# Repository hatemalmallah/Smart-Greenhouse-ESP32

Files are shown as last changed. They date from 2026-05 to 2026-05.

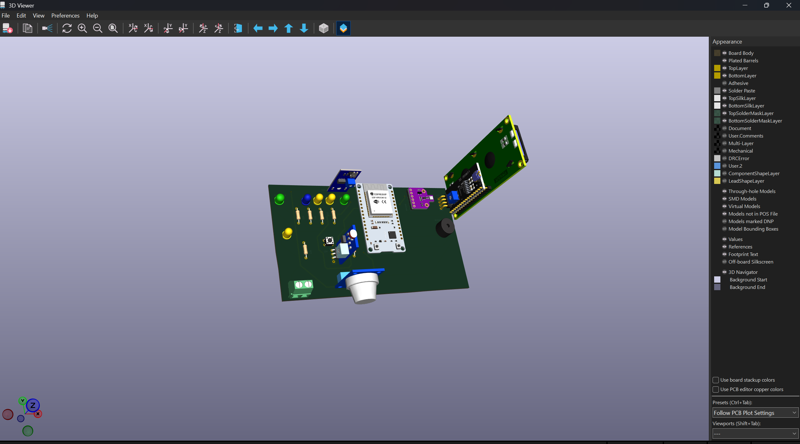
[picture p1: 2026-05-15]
Smart Greenhouse iot/image/3D PCB Design.png

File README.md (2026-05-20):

## Project Overview
This repository contains the hardware design, firmware, and IoT integration for an industrial-grade Smart Greenhouse control system. Unlike standard automated greenhouses, this project is engineered with a strong focus on **system reliability, fault tolerance, and precise actuator control**.

Powered by an **ESP32** microcontroller, the system monitors environmental parameters (Temperature, Humidity, Pressure, Gas, and Soil Moisture) via an I2C-managed **BME680** sensor. It intelligently controls 6 distinct actuators—represented by LEDs in this hardware prototype—simulating the following sub-systems: **Heating System, Cooling System, Water Pump, Grow Light, Ventilation Fan, and Humidifier**. The system manages all of these seamlessly using dual manual/automatic modes.

## Key Technical Highlights
* **Advanced Control Logic:** Implemented **Hysteresis algorithms** for stable, threshold-based actuator switching to prevent relay chattering and system instability.
* **Fault Tolerance & Safety:** Engineered a robust fail-safe mechanism. The system validates sensor data ranges, falls back to the last valid reading upon error, and executes an **Emergency Shutdown** after 5 consecutive invalid retries.
* **Signal Processing:** Utilized a Moving Average Filter (10-sample window) to clean noisy analog signals from sensors like soil moisture, preventing false triggering.
* **IoT & Remote Management:** Features bidirectional remote control via a custom **Telegram Bot API** and **Blynk** dashboard, alongside live data telemetry logged to **ThingSpeak** every 20 seconds for future Machine Learning (Predictive Maintenance) applications.
* **Custom Hardware:** Includes full PCB schematics and routing files designed specifically to handle the microcontroller, sensor bus, and actuator power management reliably.

## Hardware Components
* ESP32 Development Board (30-pin)
* BME680 Environmental Sensor
* LCD 16x2 with I2C module
* LDR Module (4-pin Photoresistor)
* 6x LED (5mm) - *Simulating Actuators*
* 6x Resistor (220 ohm)
* Buzzer (5V)
* MQ-2 Gas Sensor
* Push Button (4-pin)

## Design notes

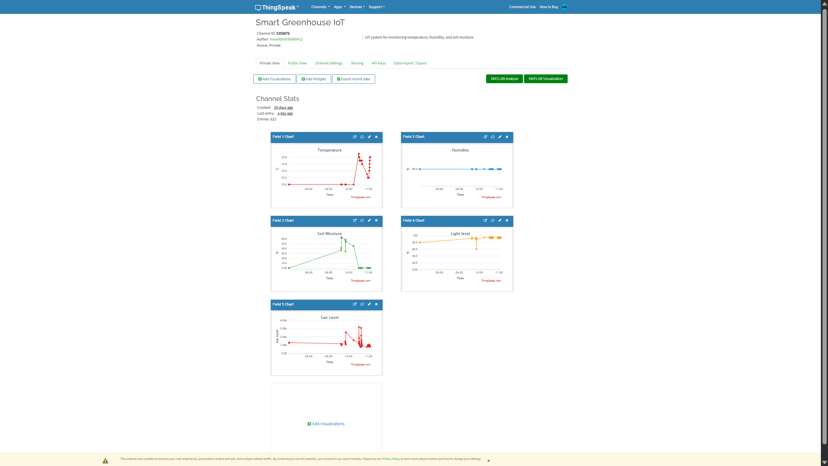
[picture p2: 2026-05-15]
Smart Greenhouse iot/image/Thingspeak .png

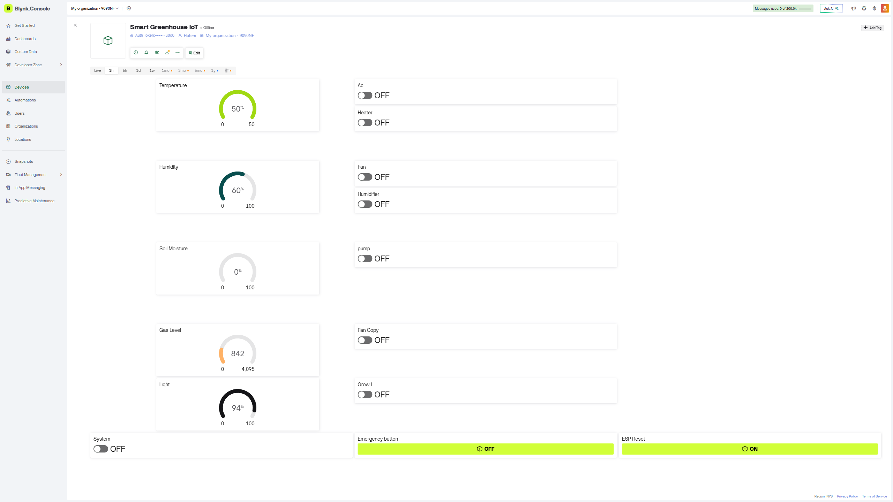
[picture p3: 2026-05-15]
Smart Greenhouse iot/image/Blynk Dashboard.png

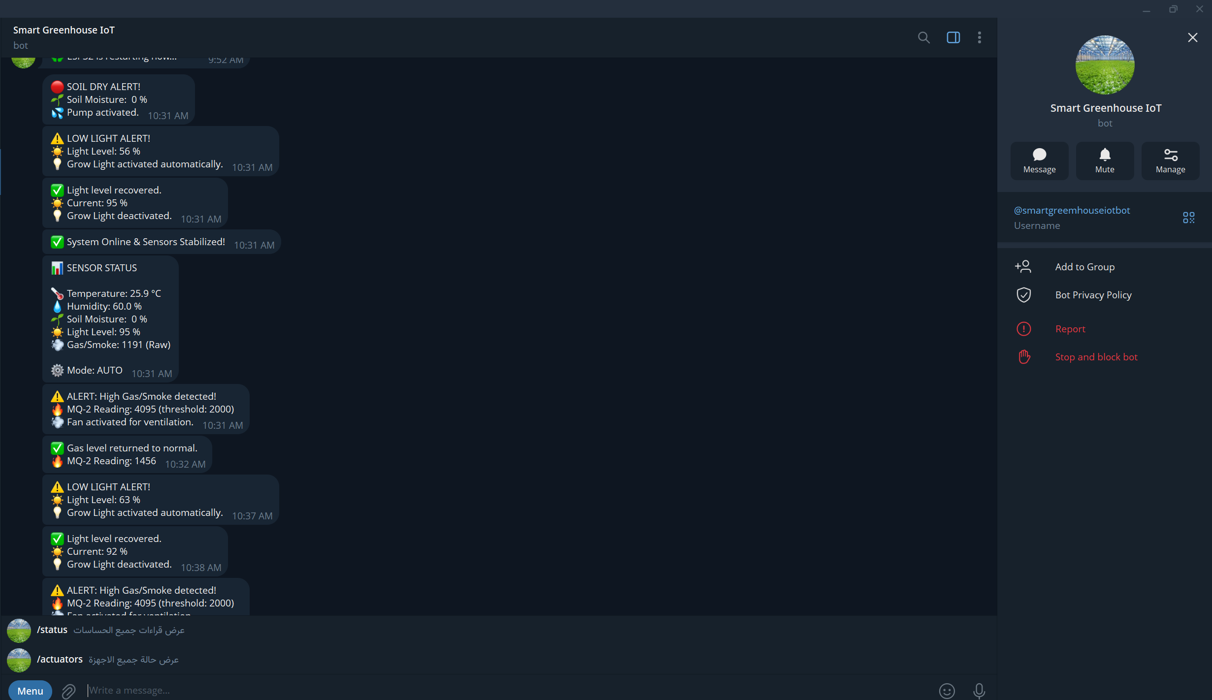
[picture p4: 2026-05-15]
Smart Greenhouse iot/image/Telegram Bot.png

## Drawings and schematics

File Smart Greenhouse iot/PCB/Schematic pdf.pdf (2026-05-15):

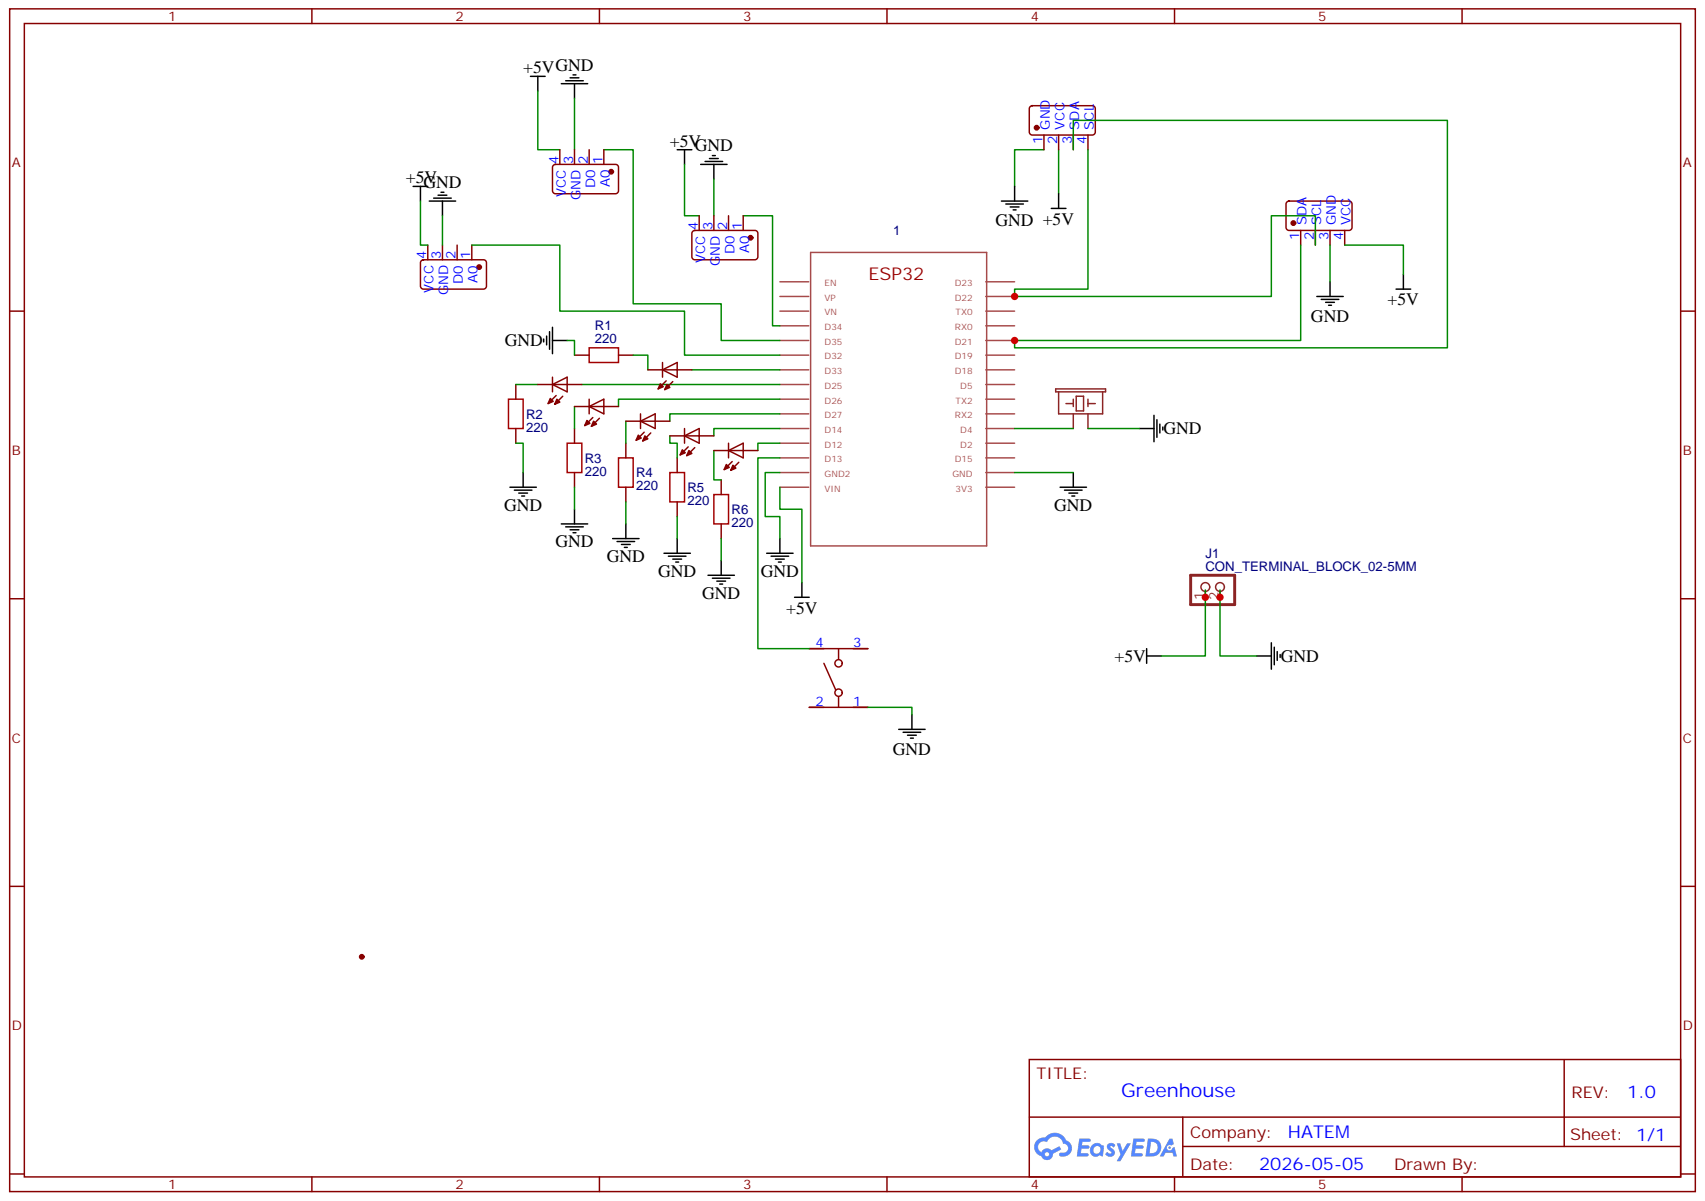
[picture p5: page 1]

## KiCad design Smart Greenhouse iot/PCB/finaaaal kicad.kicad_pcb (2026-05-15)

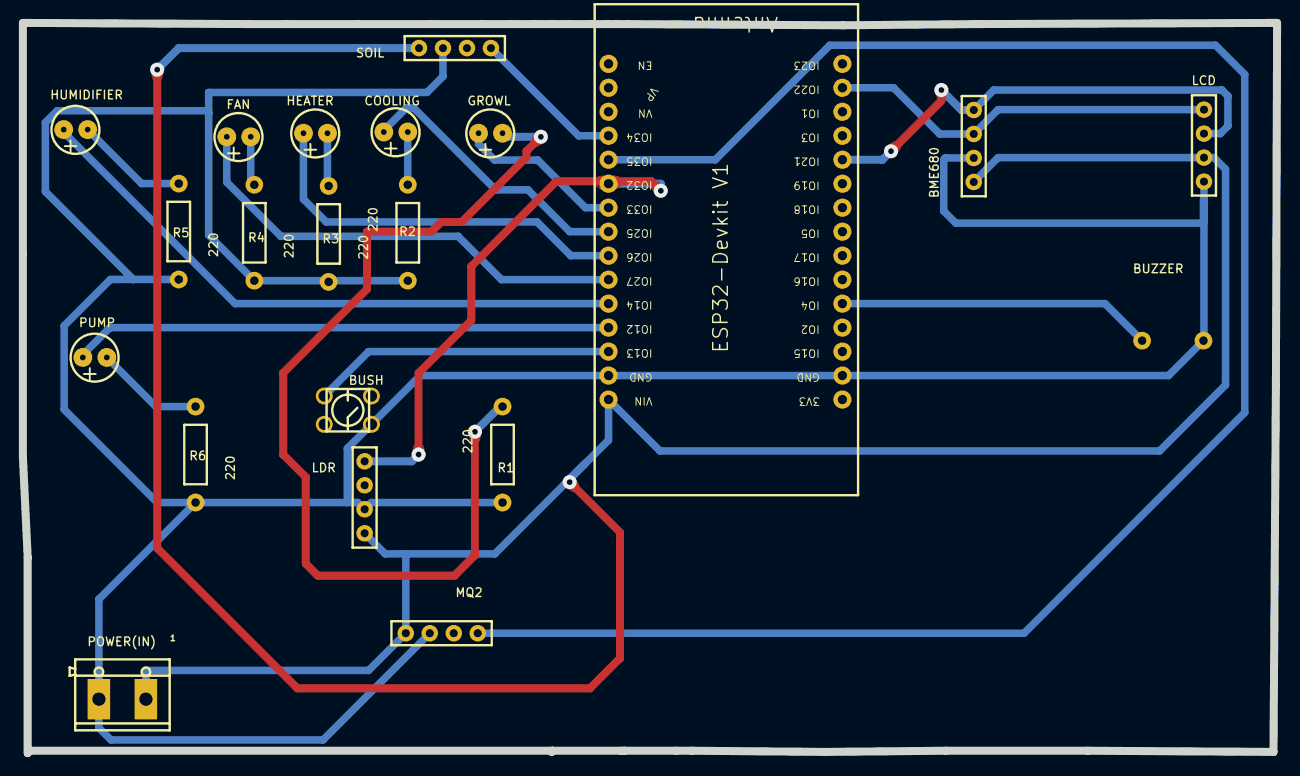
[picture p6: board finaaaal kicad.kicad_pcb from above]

Board: 2 copper layers, 132.8 x 77.3 mm, 21 parts (0 on the bottom side), 21 nets.

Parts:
BME680: Female header1*4_I2C_LCD; FEMALEHEADER1*4_I2C_GDIP
BUSH: 4.5*4.5*5 DIP TACTILE BUTTON
BUZZER: BUZZER; BUZZER-12MM-NS-KIT
COOLING: LED_5MM COPY; LED-5MM-5MM
ESP32: ESP32-DEVKIT-V1-30PIN NORMALIZED COPY; ESP32-DEVKITV1_ESP32-DEVKITV1
FAN: LED_5MM COPY; LED-5MM-5MM
GROWL: LED_5MM COPY; LED-5MM-5MM
HEATER: LED_5MM COPY; LED-5MM-5MM
HUMIDIFIER: LED_5MM COPY; LED-5MM-5MM
LCD: Female header1*4_I2C_LCD; FEMALEHEADER1*4_I2C_GDIP
LDR: Female header1*4_I2C_LCD; FEMALEHEADER1*4_I2C_GDIP
MQ2: Female header1*4_I2C_LCD; FEMALEHEADER1*4_I2C_GDIP
POWER(IN): CON_TERMINAL_BLOCK_02-5MM; TERMINAL_BLOCK_2P_5
PUMP: LED_5MM COPY; LED-5MM-5MM
R1, R2, R3, R4, R5, R6: 220; AXIAL-0.4
SOIL: Female header1*4_I2C_LCD; FEMALEHEADER1*4_I2C_GDIP

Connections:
1_D4: BUZZER.+, ESP32.D4
1_D12: ESP32.D12, PUMP.1
1_D13: BUSH.4, ESP32.D13
1_D14: ESP32.D14, HUMIDIFIER.1
1_D21: BME680.1, ESP32.D21, LCD.3
1_D22: BME680.2, ESP32.D22, LCD.4
1_D25: COOLING.1, ESP32.D25
1_D26: ESP32.D26, HEATER.1
1_D27: ESP32.D27, FAN.1
1_D32: ESP32.D32, LDR.1
1_D33: ESP32.D33, GROWL.1
1_D34: ESP32.D34, SOIL.1
1_D35: ESP32.D35, MQ2.1
+5V: BME680.4, ESP32.VIN, LCD.2, LDR.4, MQ2.4, POWER(IN).1, SOIL.4
GND: BME680.3, BUSH.1, BUZZER.-, ESP32.GND, ESP32.GND2, LCD.1, LDR.3, MQ2.3, POWER(IN).2, R1.1, R2.1, R3.2, R4.2, R5.2, R6.2, SOIL.3
R1_2: GROWL.2, R1.2
R2_2: COOLING.2, R2.2
R3_1: HEATER.2, R3.1
R4_1: FAN.2, R4.1
R5_1: HUMIDIFIER.2, R5.1
R6_1: PUMP.2, R6.1

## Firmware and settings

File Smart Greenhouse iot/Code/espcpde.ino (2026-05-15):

#define BLYNK_TEMPLATE_ID   "YOUR_BLYNK_ID"
#define BLYNK_TEMPLATE_NAME "Smart Greenhouse IoT"
#define BLYNK_AUTH_TOKEN    "YOUR_BLYNK_TOKEN"

#include <WiFi.h>
#include <WiFiClientSecure.h>
#include <BlynkSimpleEsp32.h>
#include <Wire.h>
#include <Adafruit_Sensor.h>
#include <Adafruit_BME680.h>
#include <Adafruit_BMP280.h>
#include <UniversalTelegramBot.h>
#include <ArduinoJson.h>
#include <LiquidCrystal_I2C.h>
#include <HTTPClient.h>
#include <esp_task_wdt.h>
#include <vector>

char ssid[] = "YOUR_WIFI_SSID";
char pass[] = "YOUR_WIFI_PASSWORD";

#define BOT_TOKEN   "YOUR_TELEGRAM_BOT_TOKEN"
#define DEFAULT_CHAT_ID "YOUR_CHAT_ID"

WiFiClientSecure secured_client;
UniversalTelegramBot bot(BOT_TOKEN, secured_client);

std::vector<String> knownChatIDs = {DEFAULT_CHAT_ID};
bool telegramNeedsReconnect = false;

#define THINGSPEAK_API_KEY   "YOUR_THINGSPEAK_API KEY"
#define THINGSPEAK_URL       "http://api.thingspeak.com/update"
#define THINGSPEAK_INTERVAL  20000UL
#define NETWORK_WARMUP_MS   15000UL
unsigned long lastThingSpeakSend = 0;
unsigned long wifiConnectedAt    = 0;
bool          networkReady       = false;

#define SDA_PIN       21
#define SCL_PIN       22

#define SOIL_PIN      34
#define LDR_PIN       32
#define MQ2_PIN       35

#define COOLING_PIN    25
#define HEATER_PIN     26
#define FAN_PIN        27
#define HUMIDIFIER_PIN 14
#define PUMP_PIN       12
#define GROWLIGHT_PIN  33

#define EMERGENCY_BTN_PIN  13

#define BUZZER_PIN         4

#define VPIN_TEMP         V0
#define VPIN_HUM          V1
#define VPIN_SOIL         V2
#define VPIN_COOLING_SW   V3
#define VPIN_HEATER_SW    V4
#define VPIN_FAN_SW       V5
#define VPIN_HUMIDIFIER_SW V6
#define VPIN_PUMP_SW      V7
#define VPIN_MODE         V8
#define VPIN_EMERGENCY    V9
#define VPIN_RESET        V10
#define VPIN_LIGHT        V11
#define VPIN_GAS          V12
#define VPIN_GROWLIGHT_SW V13

#define TEMP_COOL_ON    30.0f
#define TEMP_COOL_OFF   28.0f
#define TEMP_HEAT_ON    20.0f
#define TEMP_HEAT_OFF   22.0f

#define HUM_FAN_ON      80.0f
#define HUM_FAN_OFF     75.0f
#define HUM_HUMID_ON    50.0f
#define HUM_HUMID_OFF   55.0f

#define SOIL_PUMP_ON    40.0f
#define SOIL_PUMP_OFF   60.0f

#define LIGHT_GROW_ON   65.0f
#define LIGHT_GROW_OFF  75.0f

#define GAS_FAN_ON     2000
#define GAS_FAN_OFF    1500

#define TEMP_MIN_VALID   -40.0f
#define TEMP_MAX_VALID    85.0f
#define HUM_MIN_VALID      0.0f
#define HUM_MAX_VALID    100.0f
#define SOIL_MIN_VALID     0.0f
#define SOIL_MAX_VALID   100.0f

#define SENSOR_FAIL_THRESHOLD  5

#define SENSOR_INTERVAL   2000UL
#define BLYNK_INTERVAL    2000UL
#define TELEGRAM_BOT_POLL 2000UL
#define TELEGRAM_INTERVAL 1000UL
#define WARMUP_DURATION   10000UL

Adafruit_BME680 bme680;
Adafruit_BMP280 bmp280;
BlynkTimer timer;

bool useBME680  = false;
bool useBMP280  = false;
bool useDummy   = false;

#define DUMMY_TEMP       25.0f
#define DUMMY_HUMIDITY   60.0f
#define BMP280_FAKE_HUM  60.0f

LiquidCrystal_I2C lcd(0x27, 16, 2);

int lcdScreen = 0;
unsigned long lastLCDSwitch = 0;

float temperature  = 0.0f;
float humidity     = 0.0f;
float soilMoisture = 0.0f;
float lightLevel   = 0.0f;
int   gasLevel     = 0;

int  bmeFailCount  = 0;
bool bmeCritical   = false;
bool sensorFault   = false;
bool lcdAvailable  = false;

bool coolingState    = false;
bool heaterState     = false;
bool fanState        = false;
bool humidifierState = false;
bool pumpState       = false;
bool growLightState  = false;

bool manCooling    = false;
bool manHeater     = false;
bool manFan        = false;
bool manHumidifier = false;
bool manPump       = false;
bool manGrowLight  = false;

int operatingMode = 0;

volatile bool emergencyActive = false;

unsigned long bootTime       = 0;
bool          warmupComplete = false;
bool          warmupMsgSent  = false;

unsigned long buttonPressStart = 0;
bool buttonWasPressed = false;
#define LONG_PRESS_MS  3000UL

bool alertTempHigh  = false;
bool alertTempLow   = false;
bool alertHumHigh   = false;
bool alertHumLow    = false;
bool alertSoilLow   = false;
bool alertGasHigh   = false;
bool alertLightLow  = false;
bool alertAllNormal = true;

void readSensors();
void sendToBlynk();
void autoControl();
void manualControl();
void applyActuators();
void enforceSafety();
void checkAlerts();
void sendTelegram(const String &msg, const String &parseMode = "");
void setActuator(uint8_t pin, bool state);
void updateLCD();
void emergencyShutdown();
void sendToThingSpeak();
bool validateBME680(float t, float h);
void checkPhysicalEmergency();
void checkTelegramMessages();

BLYNK_WRITE(VPIN_MODE) {
  operatingMode = param.asInt();
  Serial.print("[Blynk] Mode changed → ");
  Serial.println(operatingMode == 0 ? "AUTO" : "MANUAL");
}

BLYNK_WRITE(VPIN_COOLING_SW) {
  manCooling = param.asInt();
  Serial.print("[Blynk] Manual Cooling → ");
  Serial.println(manCooling ? "ON" : "OFF");
}

BLYNK_WRITE(VPIN_HEATER_SW) {
  manHeater = param.asInt();
  Serial.print("[Blynk] Manual Heater → ");
  Serial.println(manHeater ? "ON" : "OFF");
}

BLYNK_WRITE(VPIN_FAN_SW) {
  manFan = param.asInt();
  Serial.print("[Blynk] Manual Fan → ");
  Serial.println(manFan ? "ON" : "OFF");
}

BLYNK_WRITE(VPIN_HUMIDIFIER_SW) {
  manHumidifier = param.asInt();
  Serial.print("[Blynk] Manual Humidifier → ");
  Serial.println(manHumidifier ? "ON" : "OFF");
}

BLYNK_WRITE(VPIN_PUMP_SW) {
  manPump = param.asInt();
  Serial.print("[Blynk] Manual Pump → ");
  Serial.println(manPump ? "ON" : "OFF");
}

BLYNK_WRITE(VPIN_GROWLIGHT_SW) {
  manGrowLight = param.asInt();
  Serial.print("[Blynk] Manual Grow Light → ");
  Serial.println(manGrowLight ? "ON" : "OFF");
}

BLYNK_WRITE(VPIN_EMERGENCY) {
  int val = param.asInt();
  if (val == 1) {
    Serial.println("[EMERGENCY] ⚠️ Blynk V9 emergency button PRESSED!");
    emergencyShutdown();
  }
}

BLYNK_WRITE(VPIN_RESET) {
  int val = param.asInt();
  if (val == 1) {
    Serial.println("[RESET] 🔄 Blynk V10 reset button PRESSED!");
    Serial.println("[RESET] Restarting ESP32 in 1 second...");
    sendTelegram("🔄 SYSTEM RESET requested via Blynk V10.\n"
                 "♻️ ESP32 is restarting now...");
    delay(1000);
    ESP.restart();
  }
}

BLYNK_CONNECTED() {
  Serial.println("[Blynk] Connected — syncing virtual pins…");
  Blynk.syncVirtual(VPIN_MODE);
  Blynk.syncVirtual(VPIN_COOLING_SW);
  Blynk.syncVirtual(VPIN_HEATER_SW);
  Blynk.syncVirtual(VPIN_FAN_SW);
  Blynk.syncVirtual(VPIN_HUMIDIFIER_SW);
  Blynk.syncVirtual(VPIN_PUMP_SW);
  Blynk.syncVirtual(VPIN_GROWLIGHT_SW);
  Blynk.syncVirtual(VPIN_EMERGENCY);

}

void setup() {

  Serial.begin(115200);
  delay(100);
  Serial.println();
  Serial.println("========================================");
  Serial.println("   Smart Greenhouse IoT — ESP32");
  Serial.println("   + Safety & Monitoring Layer");
  Serial.println("========================================");

  pinMode(COOLING_PIN,    OUTPUT);
  pinMode(HEATER_PIN,     OUTPUT);
  pinMode(FAN_PIN,        OUTPUT);
  pinMode(HUMIDIFIER_PIN, OUTPUT);
  pinMode(PUMP_PIN,       OUTPUT);
  pinMode(GROWLIGHT_PIN,  OUTPUT);

  digitalWrite(COOLING_PIN,    LOW);
  digitalWrite(HEATER_PIN,     LOW);
  digitalWrite(FAN_PIN,        LOW);
  digitalWrite(HUMIDIFIER_PIN, LOW);
  digitalWrite(PUMP_PIN,       LOW);
  digitalWrite(GROWLIGHT_PIN,  LOW);

  pinMode(EMERGENCY_BTN_PIN, INPUT_PULLUP);
  Serial.println("[OK] Emergency button configured (GPIO 13, INPUT_PULLUP).");

  pinMode(BUZZER_PIN, OUTPUT);
  digitalWrite(BUZZER_PIN, LOW);
  Serial.println("[OK] Buzzer configured (GPIO 4).");

  Serial.println("[I2C] Starting bus recovery...");
  Serial.flush();

  pinMode(SDA_PIN, INPUT_PULLUP);
  pinMode(SCL_PIN, OUTPUT);
  for (int i = 0; i < 16; i++) {
    digitalWrite(SCL_PIN, LOW);
    delayMicroseconds(10);
    digitalWrite(SCL_PIN, HIGH);
    delayMicroseconds(10);
  }

  pinMode(SDA_PIN, OUTPUT);
  digitalWrite(SDA_PIN, LOW);
  delayMicroseconds(10);
  digitalWrite(SCL_PIN, HIGH);
  delayMicroseconds(10);
  digitalWrite(SDA_PIN, HIGH);
  delayMicroseconds(10);

  pinMode(SDA_PIN, INPUT_PULLUP);
  pinMode(SCL_PIN, INPUT_PULLUP);
  delay(5);
  bool sdaOK = digitalRead(SDA_PIN) == HIGH;
  bool sclOK = digitalRead(SCL_PIN) == HIGH;
  Serial.printf("[I2C] Bus check: SDA=%s  SCL=%s\n",
                sdaOK ? "OK(HIGH)" : "STUCK(LOW)",
                sclOK ? "OK(HIGH)" : "STUCK(LOW)");
  Serial.flush();

  if (!sdaOK || !sclOK) {

    Serial.println("[WARN] I2C bus stuck! Sensor hardware fault.");
    Serial.println("[WARN] Skipping sensor detection — using dummy values.");
    Serial.println("Using fallback dummy sensor values");
    Serial.flush();

    useDummy    = true;
    sensorFault = true;
    temperature = DUMMY_TEMP;
    humidity    = DUMMY_HUMIDITY;

    pinMode(SDA_PIN, INPUT_PULLUP);
    pinMode(SCL_PIN, OUTPUT);
    for (int i = 0; i < 32; i++) {
      digitalWrite(SCL_PIN, LOW);
      delayMicroseconds(10);
      digitalWrite(SCL_PIN, HIGH);
      delayMicroseconds(10);
    }
    pinMode(SDA_PIN, OUTPUT);
    digitalWrite(SDA_PIN, LOW);
    delayMicroseconds(10);
    digitalWrite(SCL_PIN, HIGH);
    delayMicroseconds(10);
    digitalWrite(SDA_PIN, HIGH);
    delay(50);

  } else {

    Serial.println("[I2C] Bus is free — scanning for sensors...");
    Serial.flush();

    Wire.begin(SDA_PIN, SCL_PIN);
    Wire.setTimeOut(1000);

    bool found0x77 = false;
    bool found0x76 = false;

    Wire.beginTransmission(0x77);
    if (Wire.endTransmission() == 0) found0x77 = true;

    Wire.beginTransmission(0x76);
    if (Wire.endTransmission() == 0) found0x76 = true;

    Serial.printf("[I2C Scan] 0x76=%s  0x77=%s\n",
                  found0x76 ? "FOUND" : "---",
                  found0x77 ? "FOUND" : "---");

    if (found0x77 && bme680.begin(0x77)) {
      useBME680 = true;
      Serial.println("[OK] BME680 detected at 0x77.");
    } else if (found0x76 && bme680.begin(0x76)) {
      useBME680 = true;
      Serial.println("[OK] BME680 detected at 0x76.");
    }

    if (useBME680) {
      bme680.setTemperatureOversampling(BME680_OS_8X);
      bme680.setHumidityOversampling(BME680_OS_2X);
      bme680.setPressureOversampling(BME680_OS_4X);
      bme680.setIIRFilterSize(BME680_FILTER_SIZE_3);
      bme680.setGasHeater(0, 0);
    } else {
      Serial.println("BME680 not detected");

      if ((found0x76 && bmp280.begin(0x76)) || (found0x77 && bmp280.begin(0x77))) {
        useBMP280 = true;
        Serial.println("[OK] BMP280 detected and initialised.");
        Serial.println("[INFO] No humidity sensor — using fixed fake humidity.");

        bmp280.setSampling(Adafruit_BMP280::MODE_NORMAL,
                           Adafruit_BMP280::SAMPLING_X8,
                           Adafruit_BMP280::SAMPLING_X4,
                           Adafruit_BMP280::FILTER_X4,
                           Adafruit_BMP280::STANDBY_MS_500);
      } else {
        Serial.println("BMP280 not detected");
        useDummy = true;
        Serial.println("Using fallback dummy sensor values");
        temperature = DUMMY_TEMP;
        humidity    = DUMMY_HUMIDITY;
      }
    }

    Wire.end();
    delay(50);
  }

  pinMode(SDA_PIN, INPUT_PULLUP);
  pinMode(SCL_PIN, INPUT_PULLUP);
  delay(5);
  bool busFreeNow = (digitalRead(SDA_PIN) == HIGH && digitalRead(SCL_PIN) == HIGH);

  if (busFreeNow) {
    Wire.begin(SDA_PIN, SCL_PIN);
    Wire.setTimeOut(1000);
    Serial.println("[OK] I2C bus ready.");
    Serial.flush();

    lcd.init();
    lcd.backlight();
    lcd.setCursor(0, 0);
    lcd.print("Greenhouse");
    lcd.setCursor(0, 1);
    lcd.print("Starting...");
    lcdAvailable = true;
    Serial.println("[OK] LCD initialised.");
  } else {
    Serial.println("[WARN] I2C bus still stuck — LCD DISABLED.");
    Serial.println("[WARN] System will run without LCD display.");
    lcdAvailable = false;
  }
  Serial.flush();

  secured_client.setInsecure();
  secured_client.setTimeout(10000);

  Serial.print("[WiFi] Connecting to ");
  Serial.println(ssid);
  WiFi.begin(ssid, pass);
  Blynk.config(BLYNK_AUTH_TOKEN);

  unsigned long wifiStart = millis();
  while (WiFi.status() != WL_CONNECTED && millis() - wifiStart < 10000UL) {
    delay(500);
    Serial.print(".");
  }
  Serial.println();

  if (WiFi.status() == WL_CONNECTED) {
    Serial.println("[WiFi] ✅ Connected!");
    Serial.print("[WiFi] IP: ");
    Serial.println(WiFi.localIP());
    Blynk.connect();

    wifiConnectedAt = millis();
    networkReady = false;

    Serial.println("[Telegram] Startup message deferred until warm-up completes.");
  } else {
    Serial.println("[WiFi] ⚠️ Not connected — starting in OFFLINE mode.");
    Serial.println("[WiFi] Sensors, LCD, and emergency button work normally.");
    Serial.println("[WiFi] Cloud services will activate when WiFi connects.");
  }

  timer.setInterval(SENSOR_INTERVAL,   readSensors);
  timer.setInterval(BLYNK_INTERVAL,    sendToBlynk);
  timer.setInterval(TELEGRAM_INTERVAL, checkAlerts);
  timer.setInterval(1000L,             updateLCD);
  timer.setInterval(100L,              checkPhysicalEmergency);

  esp_task_wdt_init(30, true);
  esp_task_wdt_add(NULL);
  Serial.println("[OK] Watchdog Timer armed (30 s timeout).");

  bootTime = millis();
  warmupComplete = false;
  warmupMsgSent  = false;
  Serial.println("[OK] Sensor warm-up started (10 seconds)...");
  Serial.println("[OK] Setup complete — entering main loop.\n");
}

void loop() {

  esp_task_wdt_reset();

  if (!warmupComplete) {
    if (millis() - bootTime >= WARMUP_DURATION) {
      warmupComplete = true;
      Serial.println("[OK] ★ Sensor warm-up complete — automation ENABLED.");
    }
  }

  if (warmupComplete && !warmupMsgSent && WiFi.status() == WL_CONNECTED && networkReady) {
    warmupMsgSent = true;
    sendTelegram("\xE2\x9C\x85 System Online & Sensors Stabilized!");

    String msg = "📊 SENSOR STATUS\n\n";
    msg += "🌡️ Temperature: " + String(temperature, 1) + " °C\n";
    msg += "💧 Humidity: " + String(humidity, 1) + " %\n";
    msg += "🌱 Soil Moisture: " + String(soilMoisture, 0) + " %\n";
    msg += "☀️ Light Level: " + String(lightLevel, 0) + " %\n";
    msg += "💨 Gas/Smoke: " + String(gasLevel) + " (Raw)\n\n";
    msg += "⚙️ Mode: " + String(operatingMode == 0 ? "AUTO" : "MANUAL");
    sendTelegram(msg, "");
  }

  if (emergencyActive) {

    digitalWrite(COOLING_PIN,    LOW);
    digitalWrite(HEATER_PIN,     LOW);
    digitalWrite(FAN_PIN,        LOW);
    digitalWrite(HUMIDIFIER_PIN, LOW);
    digitalWrite(PUMP_PIN,       LOW);
    digitalWrite(GROWLIGHT_PIN,  LOW);

    static unsigned long lastBeep = 0;
    static bool beepState = false;
    if (millis() - lastBeep >= 500) {
      lastBeep = millis();
      beepState = !beepState;
      digitalWrite(BUZZER_PIN, beepState ? HIGH : LOW);
    }

    timer.run();
    return;
  }

  if (WiFi.status() == WL_CONNECTED) {

    if (!networkReady) {
      if (wifiConnectedAt == 0) wifiConnectedAt = millis();
      if (millis() - wifiConnectedAt >= NETWORK_WARMUP_MS) {
        networkReady = true;
        Serial.println("[WiFi] ★ Network warmup complete — enabling cloud services.");
      }
    }

    if (!Blynk.connected()) {
      esp_task_wdt_reset();
      Blynk.connect();
    }
    Blynk.run();
  } else {

    networkReady = false;
    wifiConnectedAt = 0;
    static unsigned long lastWiFiRetry = 0;
    if (millis() - lastWiFiRetry > 30000UL) {
      lastWiFiRetry = millis();
      Serial.println("[WiFi] ⚠️ Disconnected — retrying...");
      WiFi.begin(ssid, pass);
    }
  }

  timer.run();

  if (WiFi.status() == WL_CONNECTED && networkReady) {

    unsigned long now = millis();
    if (now - lastThingSpeakSend >= THINGSPEAK_INTERVAL) {
      lastThingSpeakSend = now;
      esp_task_wdt_reset();
      sendToThingSpeak();
    }

    static unsigned long lastBotPoll = 0;
    if (millis() - lastBotPoll >= TELEGRAM_BOT_POLL) {
      lastBotPoll = millis();
      esp_task_wdt_reset();
      checkTelegramMessages();
    }
  }
}

void checkPhysicalEmergency() {
  bool pressed = (digitalRead(EMERGENCY_BTN_PIN) == LOW);

  if (pressed && !buttonWasPressed) {

    buttonWasPressed = true;
    buttonPressStart = millis();
  }
  else if (pressed && buttonWasPressed) {

    unsigned long holdTime = millis() - buttonPressStart;

    if (holdTime >= LONG_PRESS_MS) {

      Serial.println("[RESET] 🔄 Long press detected (GPIO 13) — restarting ESP32!");

      lcd.clear();
      lcd.setCursor(0, 0);
      lcd.print("  RESTARTING  ");
      lcd.setCursor(0, 1);
      lcd.print("  Please wait ");

      sendTelegram("🔄 SYSTEM RESET via physical button (GPIO 13).\n"
                   "♻️ ESP32 is restarting now...");

      delay(500);
      ESP.restart();
    }
  }
  else if (!pressed && buttonWasPressed) {

    buttonWasPressed = false;
    unsigned long holdTime = millis() - buttonPressStart;

    if (holdTime < LONG_PRESS_MS) {

      if (!emergencyActive) {
        Serial.println("[EMERGENCY] ⚠️ Short press detected (GPIO 13) — EMERGENCY!");
        emergencyShutdown();
      } else {
        Serial.println("[EMERGENCY] Already in emergency state. Hold 3s to restart.");
      }
    }
  }
}

void emergencyShutdown() {
  emergencyActive = true;

  coolingState    = false;
  heaterState     = false;
  fanState        = false;
  humidifierState = false;
  pumpState       = false;
  growLightState  = false;

  digitalWrite(COOLING_PIN,    LOW);
  digitalWrite(HEATER_PIN,     LOW);
  digitalWrite(FAN_PIN,        LOW);
  digitalWrite(HUMIDIFIER_PIN, LOW);
  digitalWrite(PUMP_PIN,       LOW);
  digitalWrite(GROWLIGHT_PIN,  LOW);

  digitalWrite(BUZZER_PIN, HIGH);

  Serial.println("╔══════════════════════════════════════╗");
  Serial.println("║   ⚠️  EMERGENCY SHUTDOWN ACTIVE  ⚠️   ║");
  Serial.println("║   All actuators OFF — SAFE STATE     ║");
  Serial.println("║   RESET ESP32 to resume operation    ║");
  Serial.println("╚══════════════════════════════════════╝");

  if (lcdAvailable) {
    lcd.clear();
    lcd.setCursor(0, 0);
    lcd.print("!! EMERGENCY !!");
    lcd.setCursor(0, 1);
    lcd.print("ALL SYSTEMS OFF");
  }

  sendTelegram("🚨🚨 EMERGENCY SHUTDOWN ACTIVATED! 🚨🚨\n"
               "⛔ ALL actuators have been turned OFF.\n"
               "🔒 System is in SAFE STATE.\n"
               "⚠️ Manual ESP32 RESET required to resume.\n\n"
               "Trigger: " + String(digitalRead(EMERGENCY_BTN_PIN) == LOW ?
               "Physical Button (GPIO 13)" : "Software (Blynk V9 / Sensor Fault)"));
}

bool validateBME680(float t, float h) {

  if (isnan(t) || isnan(h)) {
    return false;
  }

  if (t < TEMP_MIN_VALID || t > TEMP_MAX_VALID) {
    Serial.printf("[SENSOR] ⚠️ Temperature %.1f°C out of valid range [%.0f, %.0f]\n",
                  t, TEMP_MIN_VALID, TEMP_MAX_VALID);
    return false;
  }

  if (h < HUM_MIN_VALID || h > HUM_MAX_VALID) {
    Serial.printf("[SENSOR] ⚠️ Humidity %.1f%% out of valid range [%.0f, %.0f]\n",
                  h, HUM_MIN_VALID, HUM_MAX_VALID);
    return false;
  }

  return true;
}
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
